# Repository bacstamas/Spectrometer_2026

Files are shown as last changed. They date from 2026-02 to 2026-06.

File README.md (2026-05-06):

# DIY Spectrometer – [Master’s Thesis](https://bacstamas.github.io/Spectrometer_2026/) Project

**Author:** Bács Tamás  
**Program:** Computational Physics MSc  
**University:** Babeș-Bolyai University (UBB), Faculty of Physics  

---

## 📌 Project Overview
This repository contains the complete hardware and software implementation of a low-cost DIY spectrometer. The project is developed as part of my **Master’s Thesis in Computational Physics at UBB**.

The spectrometer is built using an Arduino-based acquisition system, a multispectral sensor, custom electronics, and 3D-printed mechanical parts, with a Java-based desktop application for data visualization and analysis.

---

## 📂 Repository Structure
```
Arduino/        -> Arduino firmware for sensor acquisition and control
Java/           -> Java desktop application (GUI, data processing, visualization)
3DModels/        
 ├── FreeCAD/    -> Editable CAD source files (.FCStd)
 ├── STL/        -> 3D printable models
 └── UFP/        -> Additional fabrication/export formats
Docs/            -> Additional documents, such as images
README.md        -> Project documentation (this file)
.gitignore       -> Git ignore rules
```

---

## 🔧 Required Hardware Components
To build the spectrometer, you need the following components:

### 🧠 Electronics
- **Arduino Uno** – microcontroller for sensor control and data acquisition
- **SparkFun AS7265x Spectral Sensor** – multispectral sensor (visible)
- **BD139 NPN Transistor** – used for driving the light source
- **Light bulb with socket** – approx. **0.2 A at 5 V** (used as broadband illumination source)

### 🖨️ Mechanical Parts
- **3D printed enclosure**  
  (All CAD designs and STL files are included in the `3DModels/` directory.)
- **Spectrophotometer cuvettes**
---

## ⚡ Circuit Diagram
The following circuit is used to drive the illumination source and interface the AS7265x sensor with the Arduino:

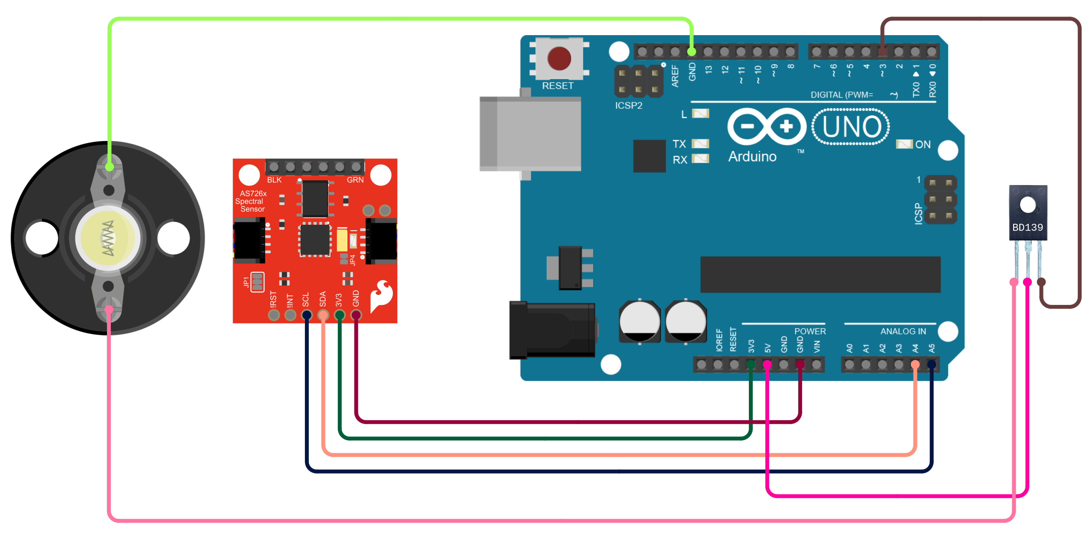
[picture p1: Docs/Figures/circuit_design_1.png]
Spectrometer Circuit Diagram


### Arduino Uno to AS7265x (I2C)

| Arduino Uno Pin | AS7265x Pin | Description |
|---|---|---|
| 5V | VIN / 5V | Sensor power supply |
| GND | GND | Common ground |
| A4 | SDA | I2C data line |
| A5 | SCL | I2C clock line |

### Arduino Uno to BD139 Transistor (Light Bulb Driver)

| Arduino Uno Pin | Component | Description |
|---|---|---|
| D3 (PWM) | BD139 Base | Controls light intensity using PWM |
| 5V | BD139 Collector | Light source supply |
| Light bulb +  | BD139 Emitter | Current flows through bulb |
| Light bulb − | GND | Common system ground |

---

## 🚀 How to Use
1. **Hardware Assembly**
   - Print the 3D models from the `3DModels/STL` folder.
   - Assemble the optical and electronic components according to the circuit diagram.

2. **Arduino Firmware**
   - Open the Arduino project in the `Arduino/` folder.
   - Upload the firmware to the Arduino Uno.

3. **Java Application**
   - Compile and run the Java GUI from the `Java/` folder.
   - The application reads spectral data from the Arduino and visualizes it.
   - Detailed documentation for the Java application can be found here: [Java App Documentation](https://bacstamas.github.io/Spectrometer_2026/JavaDocs/).

---

## 🎓 Academic Context
This project is developed as part of a **Master’s Thesis in Computational Physics** at **Babeș-Bolyai University (UBB), Faculty of Physics**.  
The goal is to design a low-cost spectrometer system and analyze its performance, calibration, and computational data processing methods.

---

## 📧 Contact
Bács Tamás  
tamas.bacs@stud.ubbcluj.ro  
Computational Physics MSc Student  
Babeș-Bolyai University

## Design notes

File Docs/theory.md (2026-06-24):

# Theoretical Background

## Spectroscopy in General

Spectroscopy is the branch of science concerned with the interaction between electromagnetic radiation and matter. When light encounters a substance, several things can happen: it may be transmitted, reflected, scattered, or absorbed, depending on the nature of the material and the wavelength of the radiation. Spectroscopy exploits these interactions to obtain information about the physical and chemical properties of substances [[2]](bibliography.md#ref2). Different regions of the electromagnetic spectrum give rise to different types of spectroscopic techniques. X-ray spectroscopy probes the inner electrons of atoms, infrared spectroscopy reveals molecular vibrations, and UV-visible spectroscopy, which is the focus of this work, involves transitions between electronic energy levels [[1]](bibliography.md#ref1). As shown in **Figure 1**, the visible spectrum occupies a narrow band of wavelengths, situated between the ultraviolet and infrared regions.

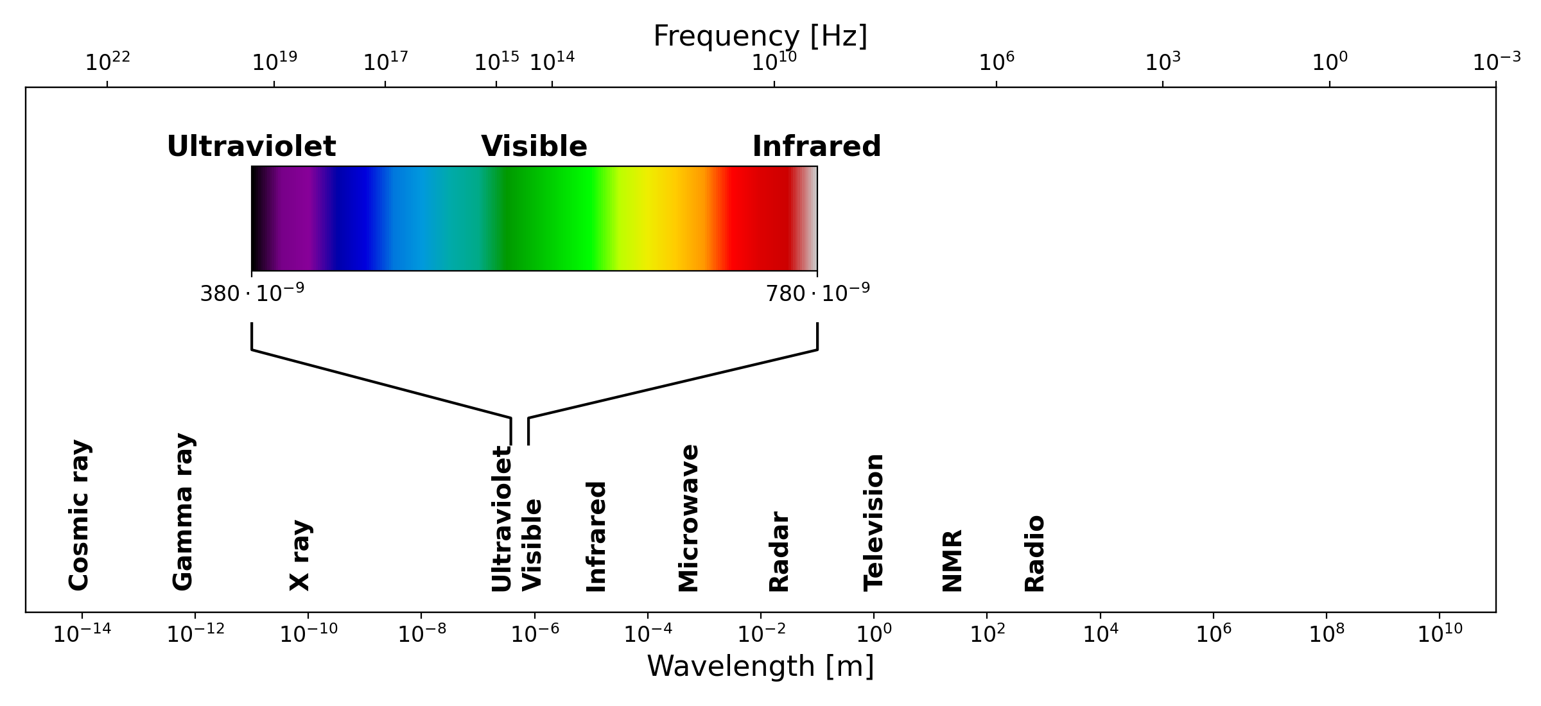
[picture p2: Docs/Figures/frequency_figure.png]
Frequency spectrum

***Figure 1**:The electromagnetic spectrum, showing the full range of radiation from cosmic rays to radio waves. The visible region, spanning approximately 380 to 780 nm, is highlighted with its characteristic color gradient. Both wavelength and frequency scales are shown*

The electromagnetic spectrum spans an enormous range of wavelengths and frequencies, from very short gamma rays at one extreme to long radio waves at the other. The UV-visible region occupies only a small portion of this spectrum, roughly from 190 nm to 800 nm, but it is particularly important because the energy of photons in this range corresponds to the energy differences between electronic states in many molecules. When a photon of the right energy strikes a molecule, it can be absorbed, promoting an electron from a lower energy level to a higher one. The wavelengths at which this absorption occurs are characteristic of the molecular structure, making UV-visible spectroscopy a powerful tool for both qualitative identification and quantitative analysis of chemical substances [[1]](bibliography.md#ref1)[[2]](bibliography.md#ref2).

## Absorption (UV/Vis) Spectroscopy

The quantitative foundation of absorption spectrophotometry is the Beer-Lambert law, which describes the relationship between the concentration of an absorbing substance and the amount of light it absorbs. To understand it, consider a beam of monochromatic light passing through a solution of an absorbing compound held in a transparent container called a cuvette [[10]](bibliography.md#ref10). Some of the light will be absorbed by the molecules in solution, and the rest will be transmitted through to the detector.

The transmittance $T$ of the solution is defined as the ratio of the transmitted light intensity I to the incident light intensity $I_0$:

$$T=\frac{I}{I_0}$$

Transmittance is often expressed as a percentage. However, for analytical purposes, it is more convenient to work with the absorbance $A$, defined as the negative logarithm of the transmittance:

$$A=-\log_{10}(T)=\log_{10}\left(\frac{I_0}{I} \right)$$

The Beer-Lambert law states that the absorbance is directly proportional to both the concentration of the absorbing species and the path length of the light through the sample:

$$A=\varepsilon\cdot l\cdot c$$

where $\varepsilon$ is the molar absorptivity (also called the molar extinction coefficient), a constant characteristic of the absorbing substance at a given wavelength, $l$ is the path length of the light through the sample, as illustrated by the cuvette width in **Figure 2** (1 cm in standard cuvettes), and $c$ is the concentration of the absorbing species. The molar absorptivity has units of $\text{L mol}^{-1} \text{cm}^{-1}$ and can vary enormously between different compounds and different wavelengths [[1]](bibliography.md#ref1).

Beer-Lambert

***Figure 2**: Schematic illustration of the Beer-Lambert law. A beam of incident light with intensity $I_0$ passes through a sample of path length $l$, emerging with reduced intensity $I$ due to absorption by the medium.*

The Beer-Lambert law is the cornerstone of quantitative spectrophotometry. If the molar absorptivity of a substance is known, measuring the absorbance of a solution immediately gives its concentration. In practice, a calibration curve is constructed by plotting the absorbance of standard solutions against their known concentrations [[10]](bibliography.md#ref10), as shown in the right panel of **Figure 3**, allowing for the determination of unknown sample concentrations via linear interpolation. The law holds well at low to moderate concentrations, but deviations can occur at high concentrations, where interactions between molecules begin to affect the absorption behavior, or when the incident light is not truly monochromatic [[1]](bibliography.md#ref1).

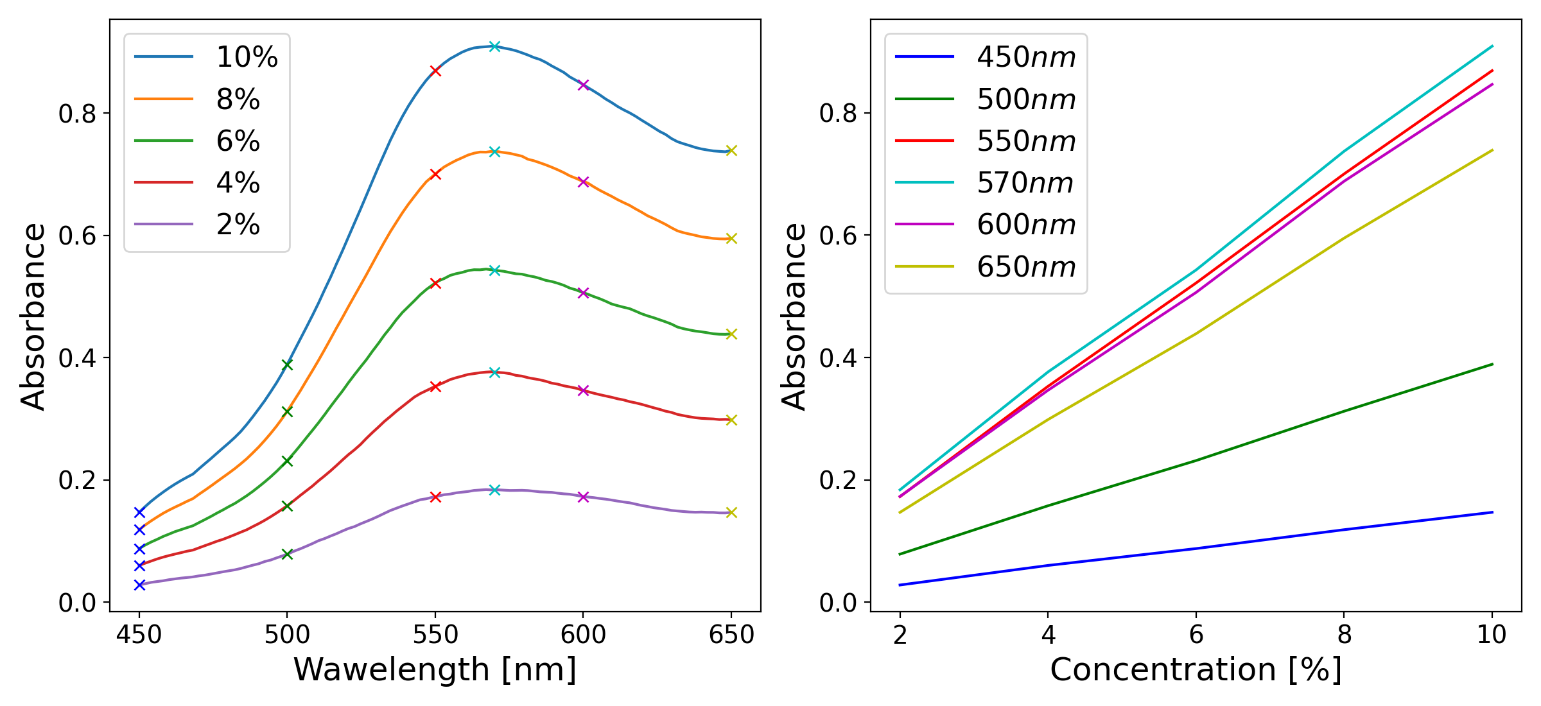
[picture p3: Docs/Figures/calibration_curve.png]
Calibration Curve

***Figure 3**: Left: example absorption spectra of a colored solution at five different concentrations, illustrating the characteristic shape of an absorption band and the increase in absorbance with concentration. Right: absorbance as a function of concentration at six specific wavelengths, illustrating the linear relationship predicted by the Beer-Lambert law.*

### Absorption Spectra and Molecular Structure

When the absorbance of a substance is measured not just at a single wavelength but across a range of wavelengths, the result is an absorption spectrum (a plot of absorbance as a function of wavelength). Each substance has a characteristic absorption spectrum that reflects its molecular structure, specifically the energies of its electronic transitions. The wavelength at which the absorbance reaches its maximum is called $\lambda_{max}$, and quantitative measurements are most sensitive at this wavelength, since small changes in concentration cause the largest changes in absorbance [[1]](bibliography.md#ref1)[[10]](bibliography.md#ref10).

The shape and position of absorption bands in the UV-visible spectrum depend on the electronic structure of the molecule. In organic molecules, the electrons most likely to be involved in UV-visible absorption are the $\pi$ electrons in conjugated systems and the non-bonding lone pair electrons on heteroatoms such as oxygen and nitrogen. As the degree of conjugation in a molecule increases, the energy gap between the ground state and the excited state decreases, and the absorption band shifts to longer wavelengths: a phenomenon known as a bathochromic or red shift. This is why, for example, beta-carotene, which has a long conjugated chain, absorbs strongly in the visible region and appears orange, while simpler molecules with fewer conjugated bonds absorb in the UV and are colorless [[1]](bibliography.md#ref1)[[10]](bibliography.md#ref10).

### Structure and Operation of Absorption Spectrometers

A UV-visible absorption spectrophotometer is an instrument designed to measure the absorbance of a sample as a function of wavelength. Despite the many variations in design and complexity that exist, all spectrophotometers share the same fundamental architecture, consisting of five basic components: a light source, a wavelength selector, a sample holder, a detector, and a readout system [[1]](bibliography.md#ref1). The spatial arrangement and theoretical operation of the primary optical components are schematically represented in **Figure 4**, with the readout system typically integrated into a modern computer interface. 

Spectrometer structure

***Figure 4**: Block diagram of the fundamental components of a single-beam absorption spectrophotometer: a light source, a monochromator for wavelength selection, a sample holder, and a detector.*

The light source must emit radiation across the entire wavelength range of interest with sufficient and stable intensity. For UV-visible spectrophotometry, two types of lamps are commonly used in commercial instruments: a deuterium lamp, which provides continuous radiation in the UV region (190–400 nm), and a tungsten-halogen lamp, which covers the visible and near-infrared region (350–900 nm). Many instruments automatically switch between the two lamps as the wavelength scan crosses the boundary between the UV and visible regions. In lower-cost and educational instruments, white LEDs are a popular alternative, as they are inexpensive, energy-efficient, and emit across much of the visible range, though with a non-uniform spectral output [[1]](bibliography.md#ref1)[[4]](bibliography.md#ref1).

The wavelength selector is the component responsible for isolating a narrow band of wavelengths from the broadband output of the light source. In modern spectrophotometers, this is almost always achieved using a diffraction grating (a flat optical surface ruled with a large number of closely spaced parallel grooves). When light strikes the grating, it is diffracted at angles that depend on its wavelength according to the grating equation:

$$n\lambda=d\sin \theta$$

where $n$ is the diffraction order (typically 1), $\lambda$ is the wavelength of the diffracted light, $d$ is the spacing between adjacent grooves, and $\theta$ is the diffraction angle. By rotating the grating or scanning the detector angle, different wavelengths can be directed onto the sample in sequence, allowing a full spectrum to be recorded. Older instruments used prisms as dispersive elements, but gratings have largely replaced them due to their more linear dispersion and lower cost [[1]](bibliography.md#ref1).

The sample holder is typically a cuvette — a small transparent container with a precisely defined path length, usually 1 cm. Cuvettes for UV measurements must be made from materials that do not absorb UV radiation, such as quartz or fused silica. For measurements confined to the visible region, less expensive plastic or glass cuvettes are perfectly adequate [[1]](bibliography.md#ref1).

The detector converts the transmitted light intensity into an electrical signal. The most common detector type in modern instruments is the photodiode, which generates a current proportional to the incident light intensity. In instruments designed to record a full spectrum simultaneously, an array of photodiodes (known as a photodiode array or PDA) can be used, replacing the need to scan through wavelengths mechanically. Photomultiplier tubes (PMTs), which offer much higher sensitivity, are used in high-end research instruments. For educational and low-cost devices, simpler detectors such as light-dependent resistors (LDRs) or phototransistors are also viable options [[1]](bibliography.md#ref1)[[4]](bibliography.md#ref4).

Finally, the readout system processes the electrical signal from the detector and presents the result to the user. In modern instruments this is handled entirely by software running on a connected computer, which can display the spectrum, perform baseline corrections, and carry out quantitative calculations automatically. In simpler home-built instruments, the detector signal is often read directly with a digital multimeter and the absorbance calculated by hand or with a simple script [[1]](bibliography.md#ref1)[[8]](bibliography.md#ref8).

It is worth noting the distinction between single-beam and double-beam instrument designs. In a single-beam spectrophotometer, the sample and the blank (a reference solution, typically the pure solvent) are measured sequentially, and the ratio of their signals gives the transmittance. In a double-beam instrument, the light is split into two paths (one through the sample and one through the reference) and both are measured simultaneously. The double-beam design is more stable against fluctuations in the light source intensity and is therefore preferred in research-grade instruments, although single-beam designs are perfectly adequate for many educational and routine analytical applications [[1]](bibliography.md#ref1)[[2]](bibliography.md#ref2).

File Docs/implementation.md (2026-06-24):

# Design and Implementation of the Spectrophotometer
## Hardware

### Idea

The starting point for the hardware design was the desire to build a functional absorption spectrophotometer that was as simple and inexpensive as possible, while remaining open to future refinement and improvement. A key decision in this direction was the choice of the SparkFun [AS7262](https://cdn.sparkfun.com/assets/f/b/c/c/f/AS7262.pdf) Visible Spectral Sensor as the core detection element. This sensor measures light intensity in six fixed channels across the visible spectrum, centered at 450, 500, 550, 570, 600, and 650 nm, and communicates digitally with a microcontroller via I2C. Its main advantage for this application is that it eliminates the need for a diffraction grating and a rotating wavelength selector entirely, the spectral discrimination is handled internally by the sensor itself. This greatly simplifies the optical layout and reduces the number of precision components required, at the cost of spectral resolution, since the instrument can only sample six discrete wavelengths rather than a continuous spectrum.

As the microcontroller, an [Arduino Uno](https://docs.arduino.cc/resources/datasheets/A000066-datasheet.pdf) was chosen. This is a natural pairing with the AS7262 sensor, as the Arduino provides the I2C interface needed to communicate with it, can supply the sensor with power, and can transfer the acquired data to a PC via its USB connection. The Arduino Uno is also widely available, inexpensive, and well documented, making it a suitable platform for an educational instrument.

For the light source, an incandescent bulb was preferred over an LED. While LEDs are cheaper and more energy efficient, their emission spectrum is strongly peaked at specific wavelengths, which can result in uneven illumination across the six detection channels of the sensor. An incandescent bulb, by contrast, emits a broad and relatively smooth blackbody-like spectrum across the entire visible range, providing more uniform illumination of all channels. The chosen bulb is a Goobay product with an E10 socket, rated at 3.5 V and 0.2 A, giving a power consumption of 0.7 W. This low current draw is important, as the 5V power pin of the Arduino Uno can supply a limited current, and exceeding it risks damaging the board.

The optical layout follows a straightforward single-beam transmission configuration. Light from the bulb passes through a vertical slit, which collimates it into a narrow beam. This beam then passes through the cuvette, which holds the sample solution. A second slit placed after the cuvette further restricts the beam before it reaches the AS7262 sensor. Standard commercial cuvettes with a 10×10 mm inner cross section and 1 cm path length were used, consistent with the standard path length assumed in Beer-Lambert law calculations. The structural frame holding all of these components together was designed in 3D modeling software and printed using a high-precision 3D printer with PLA filament, resulting in a compact enclosure slightly smaller than a 6×10×25 cm block.

### Obstacles

he development of the hardware went through two main iterations, driven by a series of practical problems encountered during testing.

The first version of the frame was modular in design, meaning that the positions of the light source, the slits, and the sensor could be adjusted along the optical axis. This was useful in the early stages of development, as it allowed the optimal spacing between components to be found experimentally. However, this first version had no cover or enclosure around the optical path, meaning that ambient light from the room could reach the sensor and contaminate the measurements. As a result, all measurements with this version had to be performed in a darkened room, which was clearly impractical for regular use.

A further issue that emerged during testing was the need to control the intensity of the light source. The AS7262 sensor has a fixed integration time and gain setting for each measurement, and if the light reaching it is too intense, the sensor saturates and the readings become unreliable. A way to reduce the light intensity without modifying the optical layout was therefore needed.

Finally, the PLA filament used for 3D printing presented an unexpected problem. The filament available was blue in color, and it turned out to be partially translucent to ambient light, allowing a non-negligible amount of stray light to penetrate the walls of the enclosure even in the second, closed version of the frame.

### Implementation

The second version of the frame addressed the problems identified during testing with the first. All components (the light source, the two slits, the cuvette holder, and the sensor) were given fixed, precisely dimensioned positions inside a closed enclosure, based on the optimal spacing determined during the first phase. The enclosure included a removable cover to allow access to the cuvette holder for changing samples, while keeping the rest of the optical path shielded from ambient light. A dedicated bay was also added to securely mount the Arduino Uno board, positioned with the USB Type-B connector accessible from the outside of the enclosure, so that the connection to the PC could be made without opening the instrument. Crucially, the Arduino was physically separated from the optical components inside the box, so that the indicator LEDs on the board would not interfere with the sensor readings. The internal structure of the assembled spectrometer is shown in **Figure 5**. 

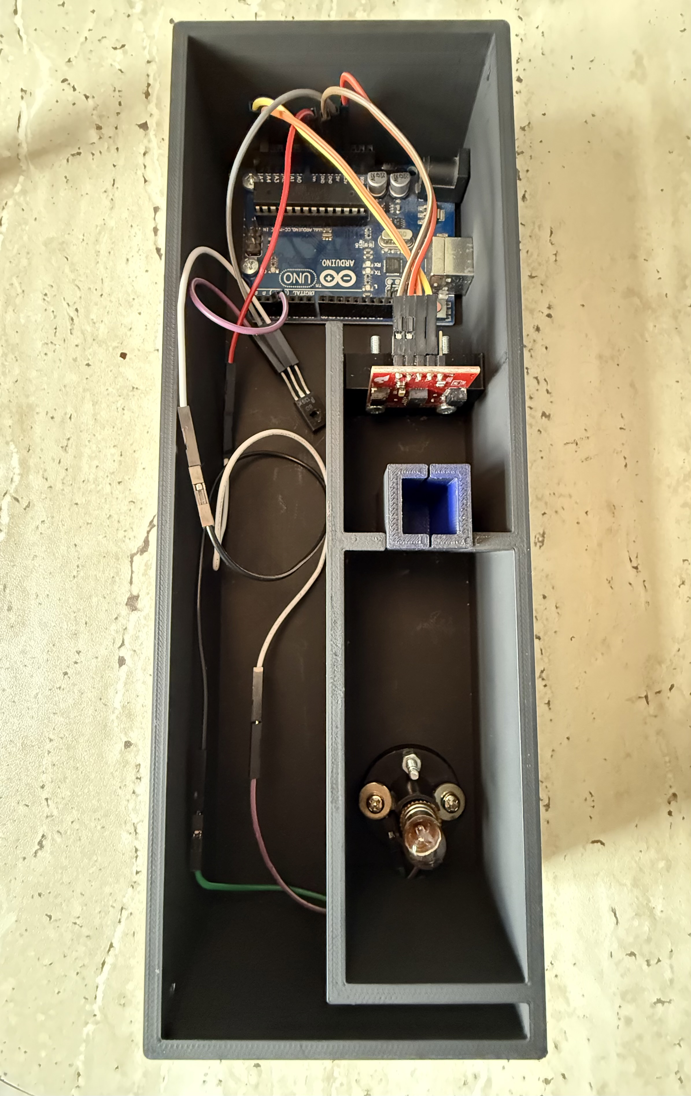
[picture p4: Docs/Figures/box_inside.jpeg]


***Figure 5**: Photo of the inside of the spectrometer.*

To solve the problem of stray light penetrating through the blue PLA walls, the exterior and interior surfaces of the enclosure were painted with a matte black paint of the type used industrially to produce surfaces with near-unity emissivity for thermal imaging applications. This paint effectively blocked the residual light transmission through the plastic walls and also minimized internal reflections within the enclosure.

The light intensity control problem was solved by adding a [BD139](https://share.google/5DOaTHuip5NTmbAFO) NPN bipolar transistor to the circuit. The transistor was wired with its collector connected to the Arduino's 5V supply pin, its emitter connected to the positive terminal of the light bulb, and the negative terminal of the bulb connected to the Arduino's ground. The base of the transistor was driven by pin 3 of the Arduino, which is a PWM-capable output. By varying the duty cycle of the PWM signal, the effective voltage across the bulb can be adjusted continuously, allowing the light intensity to be tuned to a level that keeps the sensor within its linear operating range without saturating it. This simple addition significantly improved the reliability and reproducibility of the measurements. See **Figure 6** for the circuit diagram.

Spectrometer structure

***Figure 6**: Photo of the inside of the spectrometer.*

Several sub-components, including the sensor holder, the cuvette holder, and the box cover, went through additional minor refinements beyond the two main frame iterations, as small geometric adjustments were needed to improve the fit and reduce stray light leakage around the edges. The final assembled instrument is a compact, self-contained device that can be connected to any computer via a standard USB cable and operated without any need for a darkened environment.

## Software

The software component of the spectrophotometer system consists of two separate programs: the firmware running on the Arduino microcontroller, which is responsible for directly operating the sensor and acquiring data, and a Java desktop application running on the PC, which serves as the interface between the user and the instrument. The two communicate through a serial connection over USB.

The **Arduino firmware** is intentionally kept simple and lightweight. On startup, it initializes the AS7262 sensor and sets a default configuration for the measurement parameters. It then enters a waiting loop, listening for commands arriving through the serial port.

When a measurement is requested, the command arrives as a formatted string specifying all relevant parameters: integration time, gain, number of averages, measurement mode, and light intensity. The firmware parses this string, applies the specified settings to the sensor, and adjusts the PWM signal on pin 3 to set the light source intensity accordingly. It then performs the measurement the requested number of times and computes the average across repetitions for each of the six spectral channels. The result is sent back to the PC as a single comma-separated line of six floating point values, one per channel.

The AS7262 sensor library supports two measurement modes: a raw mode, which returns the unprocessed digital counts from each photodetector channel, and a calibrated mode, which applies internal corrections to return values in units of calibrated irradiance. Both modes are accessible through the firmware and can be selected by the user from the PC software.

The **PC-side software** is written in Java, a choice motivated by several practical considerations. Java is inherently cross-platform, the same application can run on Linux, Windows, and macOS without significant modification, and it lends itself naturally to well-structured, object-oriented design that can be extended and maintained over time. The application was developed and tested on Linux but is intended to be portable across operating systems. It uses the *jSerialComm* library for serial port communication, the *XChart* library for data visualization and the *Jackson* library for handling JSON files.

The architecture of the application is organized around a small set of well-defined classes, each with a clear responsibility. This separation of concerns makes the codebase easy to navigate and extend without requiring a complete redesign.

### Structure

The *Spectrometer* class is the core of the application. It is responsible for all communication with the Arduino hardware. On instantiation, it automatically scans the available serial ports on the system (using the *jSerialComm* library) and identifies the connected Arduino by checking port descriptors and system names. Once connected, it configures the serial port parameters (baud rate, data bits, stop bits, parity) opens the connection, and flushes any startup messages sent by the Arduino. It exposes methods to configure the measurement parameters and to trigger measurements, handling the sending of the formatted command string and the reception and parsing of the response. Each call to the measurement method can request multiple spectra in sequence, each acquired with on-board averaging by the Arduino.

The *MeasurementSet* class acts as a container for all data associated with a single acquisition session. It stores the list of individual spectra recorded during that session, the full set of measurement parameters used, and a unique name composed of a user-defined label and the date and time of acquisition. It provides methods for computing the mean and standard deviation across the recorded spectra for each channel, for formatting this information as a readable string, and for saving the entire measurement set to a JSON file or loading it back from one. JSON format was chosen because it is human-readable and easy to handle.

The *Visualizer* class handles all data visualization. It takes a *MeasurementSet* as input and can produce two types of charts: a spectrum plot showing the intensity values across the six channels of the sensor, and an absorption spectrum computed from two separate measurement sets representing the reference and the sample. The absorbance at each channel is calculated according to the Beer-Lambert law as:

$$A=-\log_{10} \left(\frac{I_{sample}}{I_{reference}}\right)$$

where $I_{sample}$ and $I_{reference}$ are the mean intensities of the sample and reference measurements at each channel respectively. The *Visualizer* class uses the *XChart* library to produce the actual chart objects, which are then embedded in the GUI.

The remaining classes handle the graphical user interface. The *Main* class serves as the application entry point, launching the GUI on the appropriate thread. The *MainWindow* class implements the main application window, while the remaining classes manage the panels, menus, and dialogs, and handle specific user interactions.

### Features

The main window of the application is organized around a central list that displays all measurement sets currently loaded in memory, each identified by its unique name. From the main window, the user can connect to the spectrometer and configure the measurement parameters through a dedicated dialog, which provides input fields for integration time, gain, number of averages, number of measurements, measurement mode, and light intensity. Once configured, a measurement can be triggered with a single button press. The acquired measurement set is automatically added to the list and displayed in a text area showing its parameters and statistics.

Measurement sets can be saved to and loaded from plain text files, allowing results to be stored for later analysis or shared between sessions. The user can also load previously saved measurements without connecting to the hardware, making it possible to perform data analysis and visualization independently of the instrument.

For visualization, two separate plot types are available. The spectrum plot displays the raw or calibrated intensity values across the six sensor channels for a selected measurement set, while the absorption plot computes and displays the absorbance spectrum from a user-selected reference and sample pair. Both plot types offer configurable options accessible through dialog windows: the x-axis can be displayed in wavelength (nm) or in frequency (THz), the y-axis values can be shown as raw values or normalized to the maximum, the plot style can be switched between a line curve and a bar chart, and error bars representing the standard deviation across repeated measurements can be toggled on or off.

### Data Processing and Calibration

The data processing performed by the software is deliberately straightforward, reflecting the educational purpose of the instrument. The primary computation is the averaging of repeated spectra, which is handled partly by the Arduino firmware, which averages multiple sensor readings within a single acquisition, and partly by the *MeasurementSet* class, which computes the mean and standard deviation across multiple sequential acquisitions requested by the user. This two-level averaging scheme gives the user flexibility in balancing measurement speed against statistical reliability.

The absorbance calculation follows directly from the Beer-Lambert law, as described above. No additional baseline correction or spectral smoothing is applied, keeping the processing chain transparent and easy to follow.

## Experimental Results and Validation

With the hardware and software components completed, a series of experiments was carried out to characterize the performance of the instrument and to validate its suitability for quantitative absorbance measurements.

### Stray Light Test

The first test performed was aimed at verifying that the closed enclosure of the spectrophotometer effectively excludes ambient light. An empty cuvette was placed in the cuvette holder, the cover of the box was closed, and the light source intensity was set to 0, meaning the bulb was switched off via the PWM control. Under these conditions, repeated measurements returned a value of exactly zero on each of the six channels of the sensor. This result confirms that no stray or ambient light reaches the detector when the light source is off, validating the effectiveness of the matte black coating applied to the interior of the enclosure and ruling out the presence of any light leaks through the housing.

### Reproducibility Test

To assess the reproducibility of the measurements, a solution of yellow food coloring at a concentration of $2.5\%$ was prepared and measured repeatedly. Ten independent measurement sets were acquired, each consisting of 100 individual measurements per channel (integration time: 100 ms, gain: 16, averaging: 1, mode: raw, light intensity: 100). All ten sets were plotted together, as shown in **Figure 7**, where each of the six channels is represented by ten overlapping traces of 100 points each.

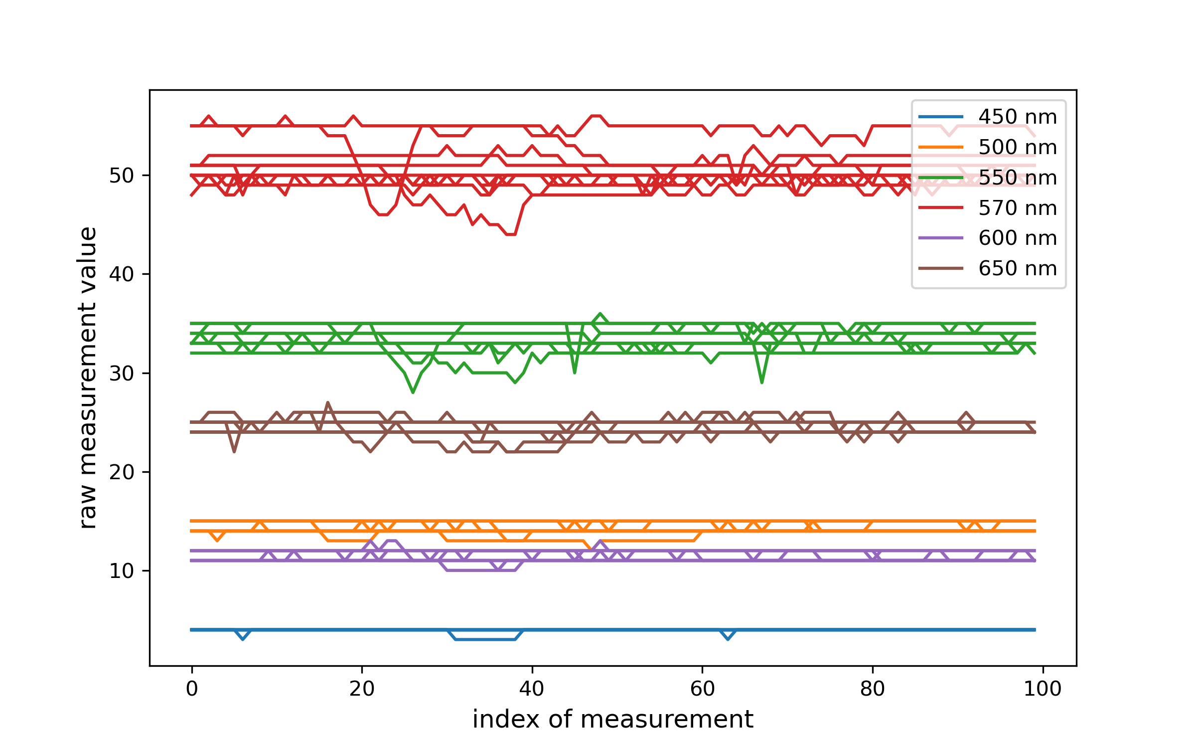
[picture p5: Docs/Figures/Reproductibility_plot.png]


***Figure 7**: Raw measurement values recorded across the six channels of the AS7262 sensor (450, 500, 550, 570, 600, and 650 nm) for ten independently acquired measurement sets of a $2.5\%$ yellow food coloring solution, each consisting of 100 individual measurements.*

The plot shows that the measured values remain clustered around a stable baseline for each channel, with some random scatter present throughout the dataset. Averaging across all 1000 individual measurements per channel (10 sets × 100 measurements), the mean raw values obtained were *{3.99, 14.251, 33.428, 50.629, 11.336, 24.334\}* for the *450, 500, 550, 570, 600* and *650* nm channels respectively, with corresponding standard deviations of *{0.099, 0.522, 1.101, 2.004, 0.501, 0.696\}*. The relative standard deviation remains below approximately $4\%$ for every channel, which indicates a satisfactory level of reproducibility for an instrument of this cost and complexity. This noise may be attributable to small imperfections such as scratches on the cuvette surface and slight variations in its exact positioning within the holder between insertions.

### Long-Term Stability Test

A further test was conducted to check whether the solution itself remained stable over time, an important consideration since sedimentation or settling of the food coloring could introduce a systematic drift in absorbance unrelated to the instrument's performance. The same yellow food coloring solution and the same measurement parameters used in the reproducibility test were employed. A cuvette containing the solution was measured once, left undisturbed inside the instrument for 24 hours, and then measured again without being touched or repositioned in between. The difference between the two measurements was found to be smaller than the standard deviations already observed in the reproducibility test, indicating that no significant settling or degradation of the solution occurred over this timescale, and that any short-term drift in the instrument's readings is dominated by the handling-related noise identified above rather than by sample instability.

### Calibration Curves

Finally, the linearity of the instrument's response was tested by preparing a series of yellow food coloring solutions at concentrations ranging from $0.8\%$ to $10\%$, and measuring the absorbance of each at all six sensor channels. The resulting calibration curves are shown in **Figure 8** (one subplot for each channel) together with a linear best-fit line.

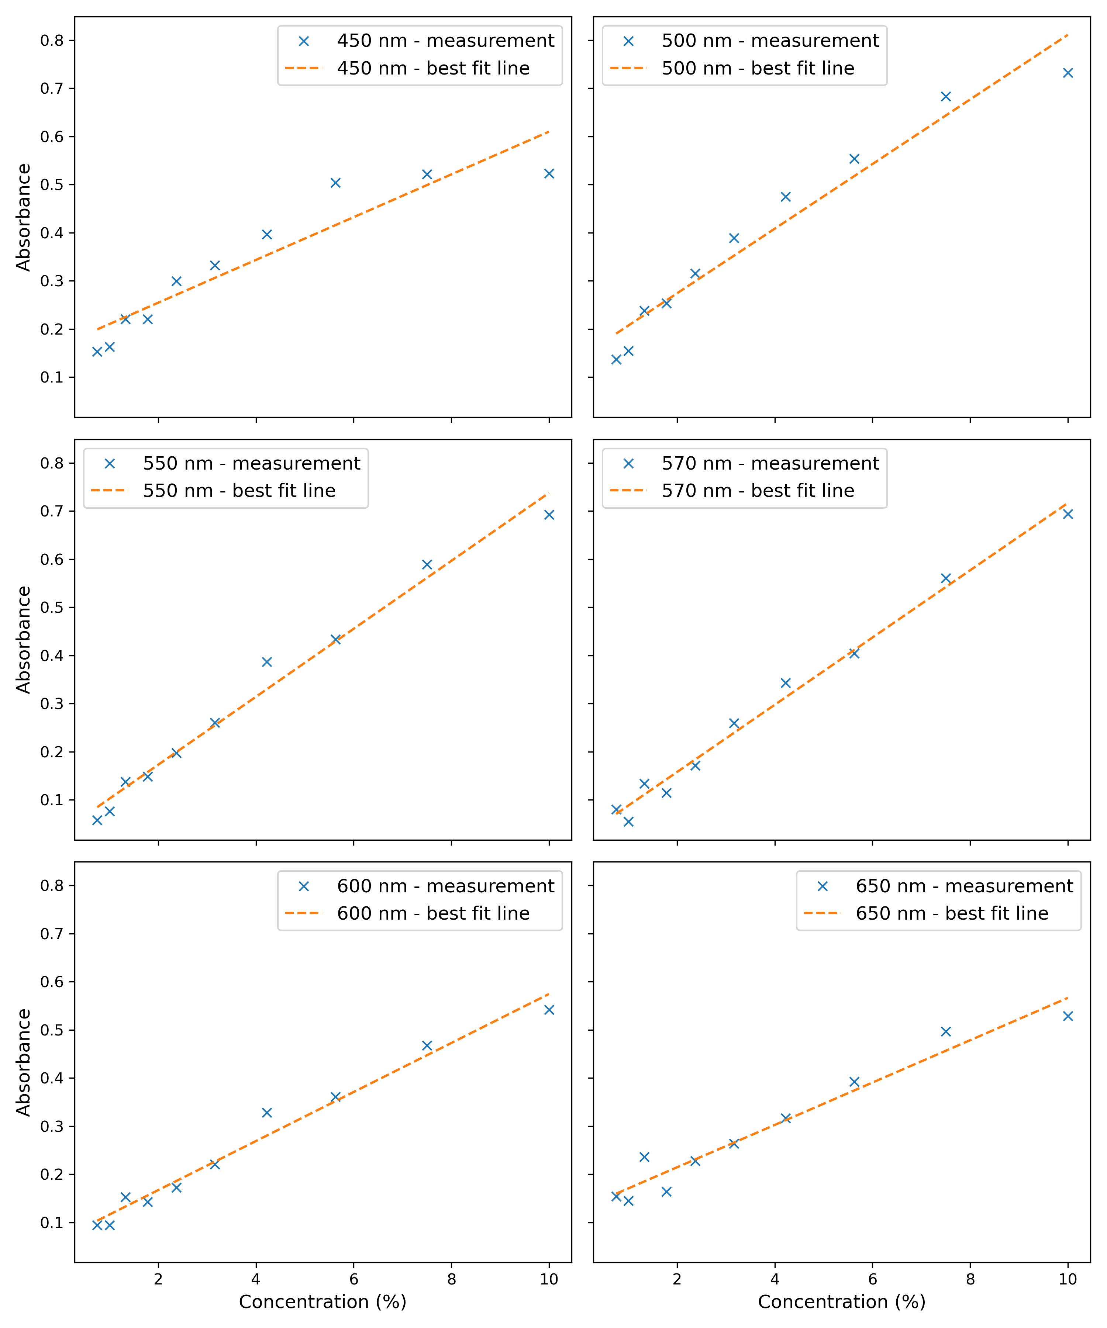
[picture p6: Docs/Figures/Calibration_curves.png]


***Figure 8**: Six calibration curves showing absorbance against concentration ($\%$), along with their corresponding best-fit lines, at each of the sensor's wavelengths.*

Across all six channels, the measured absorbance values follow the linear trend predicted by the Beer-Lambert law reasonably well, particularly in the central concentration range. Some scatter around the fitted line is visible, which is consistent with the absolute measurement noise identified in the reproducibility test. The channels at *550, 570* and *600* nm, which are closer to the absorption maximum of the yellow dye, display the clearest linear behavior and the largest overall absorbance range, while the *450* nm channel, which lies further from the absorption peak, shows comparatively more scatter relative to its smaller dynamic range. Overall, these results confirm that the constructed instrument is capable of producing calibration curves with a clearly recognizable linear character across the entire visible range covered by the sensor, supporting its intended use for quantitative concentration measurements in an educational context.

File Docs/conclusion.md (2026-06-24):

# Conclusion
The primary objective of this thesis was the design, construction, and validation of a low-cost absorption spectrophotometer intended for educational use. The developed instrument combines simple hardware with dedicated software for data acquisition, visualization, and absorbance calculation. Experimental testing demonstrated that the spectrometer is capable of producing reproducible measurements and calibration curves that follow the linear behavior predicted by the Beer-Lambert law. While the measurements exhibit a non-negligible level of noise, the results show that the instrument is sufficiently reliable for educational and demonstration purposes, provided that appropriate care is taken during sample preparation and measurement.

One of the main strengths of the instrument is its combination of low cost and transparency. Unlike commercial spectrophotometers, whose internal operation is often hidden from the user, the present design exposes the essential elements of an absorption measurement system and makes the underlying physical principles easier to understand. As a result, the spectrometer is well suited for use in secondary-school and undergraduate laboratory activities. Students can gain practical experience with solution preparation, reference measurements, absorbance calculations, the construction of calibration curves, and the quantitative determination of concentrations. More advanced educational projects could even include the determination of the molar absorptivity of a substance through Beer-Lambert analysis.

Beyond its use as a measurement instrument, the reproduction of the spectrometer itself could serve as a valuable educational project for physics students at the BSc or MSc level. Constructing the device requires engagement with several important areas of modern scientific and engineering practice, including absorption spectroscopy, 3D design and printing, microcontroller programming, object-oriented software development, and experimental testing. The process of building and validating the instrument provides a deeper understanding of both the physical principles and the practical challenges involved in spectroscopic measurements.

Although the instrument successfully fulfills its intended educational purpose, several opportunities for further development remain. One possible improvement would be the replacement of the AS7262 sensor with a sensor offering a larger number of spectral channels, increasing the spectral resolution of the measurements. Another possibility would be to adopt a more traditional spectrometer architecture based on a rotatable diffraction grating and a simpler photodetector, allowing the acquisition of a continuous spectrum rather than measurements at six discrete wavelengths. Such modifications could improve the analytical capabilities of the instrument while preserving its educational value.

A particularly promising direction for future development would be the replacement of the Arduino Uno with an ESP32 microcontroller. The additional processing power and built-in Wi-Fi connectivity of the ESP32 would make it possible to implement the user interface as a web application hosted directly by the instrument. In such a design, users could access the spectrometer through any device equipped with a web browser, without the need to install dedicated software. This would simplify deployment in classroom environments, reduce platform-dependence, and further increase the accessibility of the system.

In conclusion, the developed spectrophotometer demonstrates that quantitative absorption measurements can be achieved with inexpensive and widely available components. Although it cannot compete with commercial instruments in terms of precision or spectral resolution, it successfully fulfills its intended role as an educational tool and provides a practical platform for teaching both spectroscopy and scientific instrumentation.

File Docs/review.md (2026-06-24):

# Review of Low-Cost / DIY Spectrophotometers

The development of low-cost and home-built spectrophotometers has been an active area of interest in the educational and scientific community for several decades. The motivations behind these efforts are clear: commercial instruments are often prohibitively expensive for schools and smaller institutions, and even when available, they offer little insight into the physical principles of the measurement. A wide variety of designs have been proposed over the years, differing in complexity, cost, target audience, and performance. This section reviews the most relevant examples from the literature, with particular attention to the design choices made and the lessons that can be drawn for the present work.

One of the earliest and most accessible designs is that described by Lema et al. [[6]](bibliography.md#ref6), who built a spectrophotometer from components readily available to anyone: a halogen flashlight as the light source, a compact disc (CD) as the diffraction element, a light-dependent resistor (LDR) as the detector, and a standard digital multimeter for readout. The entire assembly was mounted in a cardboard box, with two simple slits used to collimate the diffracted light onto the detector. Despite its extreme simplicity, this device was capable of producing recognizable absorption spectra and calibration curves for several biochemically relevant substances, including chlorophyll, starch, and proteins. The authors demonstrated its use in a series of teaching experiments in a biosciences course, showing that meaningful quantitative results could be obtained even with such minimal means. The main limitation of this design is its poor wavelength resolution (rotating the CD by a single degree corresponds to a wavelength change of approximately 25 nm) and the fact that it provides resistance readings rather than direct absorbance values. Nevertheless, it remains a compelling demonstration of how far ingenuity can go in replacing expensive equipment [[6]](bibliography.md#ref6).

A more structured approach was taken by Knagge and Raftery [[7]](bibliography.md#ref7), who designed a LEGO-based spectrophotometer for use in a graduate-level chemical instrumentation course at Purdue University. Their instrument incorporated a miniature filament lamp as the light source, a convex lens and an infrared filter for light conditioning, a 1000 lines/mm transmission diffraction grating, a spring-loaded rotating mirror for wavelength selection, a silicon photodetector, and an amplifier circuit connected to a digital multimeter. The use of LEGO bricks as optical mounts was motivated by their precise manufacturing tolerances, modularity, and mechanical stability, which make them well suited to holding optical components in alignment. The instrument achieved a wavelength resolution of approximately 8 nm and was used to record absorption spectra and calibration curves for potassium permanganate. Compared to a commercial Spectronic 20 instrument, the home-built device showed higher stray light levels and a higher limit of detection, but its calibration curves displayed similar linearity. The total cost was approximately 200 USD. The authors emphasized that the educational value of the device lay not only in its use, but in the process of construction itself, through which students gained practical experience with the optical and electronic modules that make up any analytical instrument [[7]](bibliography.md#ref7).

Building on the LEGO concept but targeting a much younger and less specialized audience, Albert, Todt, and Davis [[8]](bibliography.md#ref8) developed a significantly simpler and cheaper LEGO spectrophotometer designed for use in high school physics and chemistry classes. Their design used a white LED as the light source, a single lens for collimation, a 1000 lines/mm slide-mounted diffraction grating, and a photodiode mounted on a rotatable arm for wavelength selection, with a digital multimeter as the readout. The entire apparatus was built on a standard LEGO baseplate and could be assembled and optimized in approximately 45 minutes. The total cost was around 25 USD, roughly one eighth of the cost of the Knagge and Raftery design. Despite its simplicity, the device produced absorbance measurements in close agreement with those from a commercial Ocean Optics USB2000+ spectrophotometer over the typical working range of absorbance values up to about 1, and was capable of recording full visible absorption spectra between approximately 420 and 660 nm. The authors noted that the use of familiar toy materials made the activity engaging for students, and that the transparent design effectively exposed the physical principles that are hidden in commercial black-box instruments [[8]](bibliography.md#ref8).

A very different approach is represented by the work of Wang et al. [[9]](bibliography.md#ref9), who demonstrated a smartphone-based spectrometer for colorimetric biosensing applications. Their device used the built-in LED flash of a smartphone as the light source, a compact disc fragment as the diffraction grating, and the smartphone's CMOS camera as the detector. The entire optical assembly was compact and required no external components beyond a simple sample cell. The smartphone camera captured the dispersed spectrum as an image, which was then processed using a dedicated Android application to extract the absorbance spectrum. The device was tested for the detection of glucose using an enzymatic colorimetric assay and for the detection of cardiac troponin I using peptide-functionalized gold nanoparticles, achieving limits of detection comparable to those of commercial bench-top instruments. While this design is more oriented toward portable point-of-care diagnostics than classroom education, it illustrates the remarkable potential of consumer electronics as spectroscopic platforms, and it highlights the growing role of smartphones and digital cameras as detectors in low-cost spectrophotometry [[9]](bibliography.md#ref9).

González-Morales et al. [[3]](bibliography.md#ref3) presented a portable low-cost UV-Vis spectrophotometer specifically designed for field measurements of environmental contaminants, with a particular application to the detection of mercury ions in water using a synthesized chemosensor. Their instrument operated in the visible range from 400 to 700 nm and used a 1 W white LED as the light source, a DVD-derived diffraction grating mounted on a stepper motor for automated wavelength scanning, and a TEMT6000 phototransistor as the detector. The entire device was housed in a 3D-printed black enclosure and controlled by an Arduino microcontroller, which performed the wavelength sweep, acquired the detector signal, computed the absorbance, and transmitted the data to a computer. Two independent sample chambers allowed simultaneous measurement of the sample and a reference, improving stability. The total cost of the device was below 86 USD. Absorbance measurements agreed with those from a commercial Cary 60 spectrophotometer with error percentages below $10\%$ for most concentrations, and below $5\%$ for the mercury detection experiments. This design is particularly noteworthy for its level of integration and automation, demonstrating that a microcontroller-based instrument can approach commercial performance at a small fraction of the cost [[3]](bibliography.md#ref3).

Finally, the Viking spectrophotometer developed by Kolesnichenko et al. [[5]](bibliography.md#ref5) represents one of the most pedagogically sophisticated examples in the recent literature. Rather than aiming for maximum analytical performance, this design prioritized the learning experience above all else. The instrument was built from wooden holders, inexpensive magnifying glass lenses, a white LED light source with a replaceable aluminum foil slit, and a transmission diffraction grating mounted in a slide frame. Crucially, no fixed housing was used, all components were freely positioned on a flat table, allowing students to experiment with different configurations, observe the effects of misalignment, and develop genuine physical intuition. The spectrum was projected onto a white cardboard screen and photographed with a smartphone camera for digitization. The device supported both absorption and fluorescence measurements and was successfully deployed across a wide range of educational levels, from high school outreach activities to Master and PhD level courses at Lund University. Its total material cost was approximately 14 euros per set. The authors reported that engagement with the Viking spectrophotometer measurably improved the quality of students' laboratory reports and their confidence when subsequently operating professional instruments [[5]](bibliography.md#ref5).

Taken together, these examples illustrate that low cost and high educational value are not mutually exclusive, and that the integration of a microcontroller with dedicated software can dramatically extend the functionality of a home-built device without greatly increasing its cost. These considerations have directly shaped the design decisions described in the following chapter.

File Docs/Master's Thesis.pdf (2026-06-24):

## BABES, -BOLYAI UNIVERSITY

# Master’s thesis

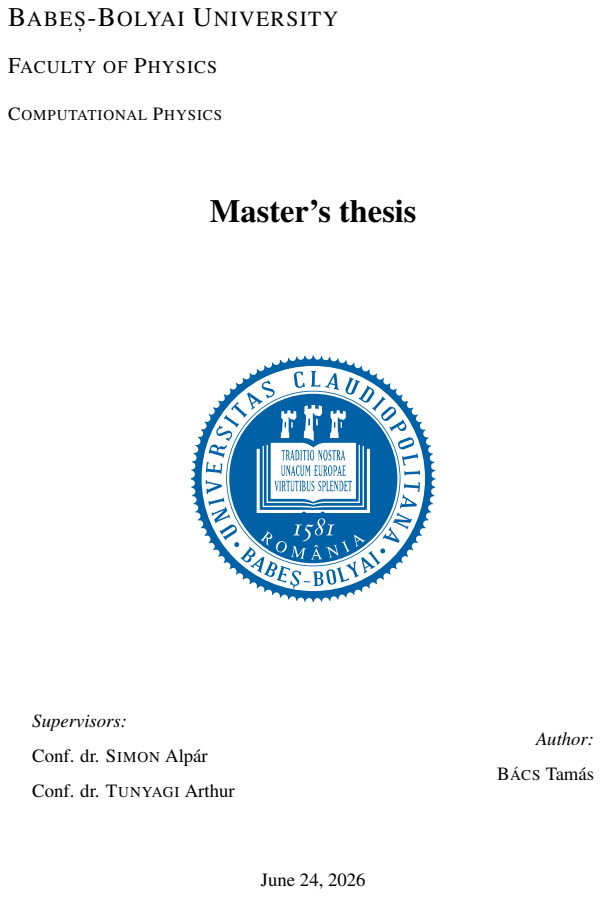
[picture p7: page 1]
COMPUTATIONAL PHYSICS; Supervisors:; Author:; BÁCS Tamás; June 24, 2026

FACULTY OF PHYSICS

Conf. dr. SIMON Alpár

Conf. dr. TUNYAGI Arthur

## BABES, -BOLYAI UNIVERSITY

# Master’s thesis

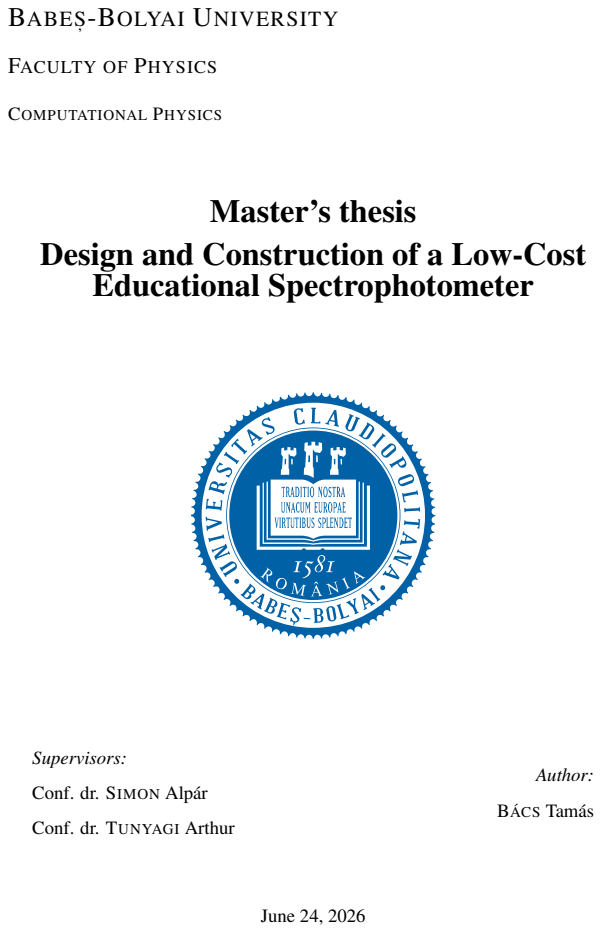
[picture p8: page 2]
COMPUTATIONAL PHYSICS; Supervisors:; Author:; BÁCS Tamás; June 24, 2026

FACULTY OF PHYSICS

Design and Construction of a Low-Cost
Educational Spectrophotometer

Conf. dr. SIMON Alpár

Conf. dr. TUNYAGI Arthur

## Contents

Introduction and Objectives | 4
1 Theoretical Background | 6
2 Review of Low-Cost / DIY Spectrophotometers | 12
3 Design and Implementation of the Spectrophotometer | 15
Conclusion | 26
References | 28

BÁCS Tamás | Design and Construction of a Low-Cost Educational Spectrophotometer

## Introduction and Objectives

Since vision is one of our most important and highly developed senses, it is natural that humans

have long sought to build instruments capable of performing similar tasks in a quantitative and

objective manner. Just as the human eye can often provide a qualitative impression of whether

a sample of water is clean or contaminated, a spectrophotometer can analyze the interaction of

light with matter and provide quantitative information about the composition and concentration of

substances dissolved in a solution. This is widely used in chemistry, biology, medicine, and en-

vironmental monitoring. In particular, UV-visible (UV-Vis) absorption spectrophotometry is built

on the Beer-Lambert law, which states that the amount of light absorbed by a solution is propor-

tional to the concentration of the absorbing substance. This makes it an indispensable tool in both

research and educational settings, where it underlies experiments ranging from the quantification

of biomolecules to the study of reaction kinetics [1][2].

Despite its importance, access to absorption spectrophotometry is far from universal. Com-

mercial UV-Vis spectrophotometers, while offering excellent performance, are expensive instru-

ments that many schools and universities, particularly those with limited budgets, cannot afford [3].

Beyond the financial barrier, modern commercial instruments present a further challenge in edu-

cational contexts: they function as so-called "black boxes", hiding from the user the physical

principles that underlie the measurement. Students who interact only with polished commercial

devices are often left with little understanding of how a spectrum is actually generated, what role

the diffraction grating plays, or why alignment and calibration matter [4][5]. This gap between

instrument use and instrument understanding is a genuine obstacle to deep learning in physics and

chemistry education.

In response to these challenges, a growing body of work over the past two decades has explored

the construction of low-cost, home-built spectrophotometers for educational use. These range from

very simple devices assembled from compact discs, flashlights, and cardboard [6], to more refined

systems built from LEGO bricks [7][8], 3D-printed parts [4], or smartphone platforms [9]. A com-

mon finding in this literature is that building an instrument from scratch (selecting components,

aligning optics, calibrating the wavelength scale, and troubleshooting) provides a qualitatively

richer learning experience than simply operating a commercial device. Students who build their

own spectrophotometers develop a hands-on understanding of diffraction, Beer-Lambert behavior, and sources of experimental error that would otherwise remain abstract [5][8]. At the same time,

these devices can bring quantitative spectroscopic measurement within financial reach of institu-

tions that would otherwise have none [6].

The present thesis is situated within this context. The goal was to design, construct, and char-

acterize a low-cost absorption spectrophotometer intended primarily for educational use. The in-

strument is developed with transparency in mind: every component is chosen and arranged so as

to make the underlying physics as visible and understandable as possible to anyone assembling

or using it. Alongside the hardware, a dedicated software system is developed to handle data

acquisition, wavelength calibration, and the computation of absorbance spectra [4].

More specifically, the thesis begins by reviewing the theoretical foundations of UV-Vis ab-

sorption spectroscopy, including the Beer-Lambert law and the general operating principles of

spectrophotometric instruments. It then surveys existing low-cost and DIY spectrophotometer de-

signs from the literature, identifying key design choices and their trade-offs. The bulk of the work

describes the hardware and software of the constructed instrument in detail, including the prac-

tical obstacles encountered and the solutions adopted. Finally, the performance of the device is

validated through experimental measurements, and its limitations and potential improvements are

discussed [10].

By addressing these objectives, this thesis aims to contribute to the broader effort of making

spectroscopic measurement accessible, transparent, and educationally meaningful — an effort that

is increasingly recognized as valuable not only in chemistry, but in physics education as well [4][5].

## 1 Theoretical Background

### 1.1 Spectroscopy in General

Spectroscopy is the branch of science concerned with the interaction between electromagnetic

radiation and matter. When light encounters a substance, several things can happen: it may be

transmitted, reflected, scattered, or absorbed, depending on the nature of the material and the

wavelength of the radiation. Spectroscopy exploits these interactions to obtain information about

the physical and chemical properties of substances [2]. Different regions of the electromagnetic

spectrum give rise to different types of spectroscopic techniques. X-ray spectroscopy probes the

inner electrons of atoms, infrared spectroscopy reveals molecular vibrations, and UV-visible spec-

troscopy, which is the focus of this work, involves transitions between electronic energy levels [1].

As shown in Figure 1.1, the visible spectrum occupies a narrow band of wavelengths, situated

between the ultraviolet and infrared regions.

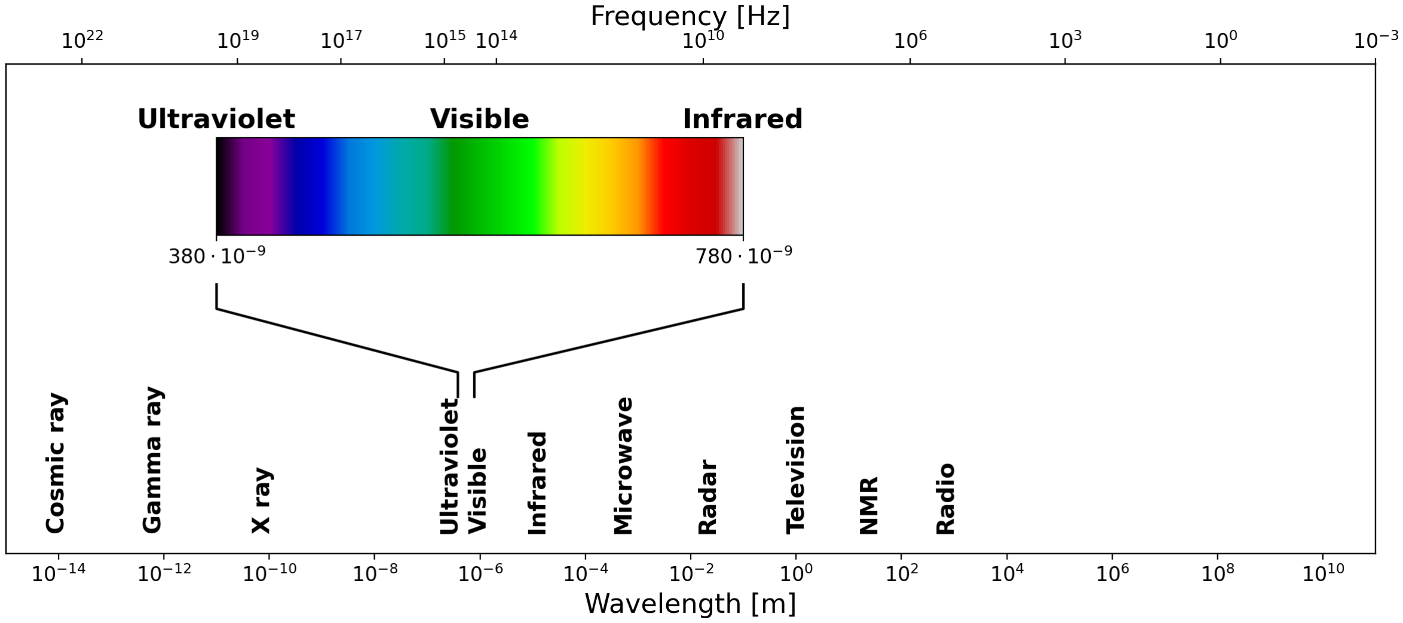
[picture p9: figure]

Figure 1.1: The electromagnetic spectrum, showing the full range of radiation from cosmic rays

to radio waves. The visible region, spanning approximately 380 to 780 nm, is highlighted with its

characteristic color gradient. Both wavelength and frequency scales are shown.

The electromagnetic spectrum spans an enormous range of wavelengths and frequencies, from

very short gamma rays at one extreme to long radio waves at the other. The UV-visible region oc-

cupies only a small portion of this spectrum, roughly from 190 nm to 800 nm, but it is particularly important because the energy of photons in this range corresponds to the energy differences be-

tween electronic states in many molecules. When a photon of the right energy strikes a molecule,

it can be absorbed, promoting an electron from a lower energy level to a higher one. The wave-

lengths at which this absorption occurs are characteristic of the molecular structure, making UV-

visible spectroscopy a powerful tool for both qualitative identification and quantitative analysis of

chemical substances [1][2].

### 1.2 Absorption (UV/Vis) Spectroscopy

The quantitative foundation of absorption spectrophotometry is the Beer-Lambert law, which de-

scribes the relationship between the concentration of an absorbing substance and the amount of

light it absorbs. To understand it, consider a beam of monochromatic light passing through a solu-

tion of an absorbing compound held in a transparent container called a cuvette [10]. Some of the

light will be absorbed by the molecules in solution, and the rest will be transmitted through to the

detector.

The transmittance T of the solution is defined as the ratio of the transmitted light intensity I to

the incident light intensity I0:

T =

I
I0

(1)

Transmittance is often expressed as a percentage. However, for analytical purposes, it is more

convenient to work with the absorbance A, defined as the negative logarithm of the transmittance:

A = −log10(T) = log10
I0
I
(2)

The Beer-Lambert law states that the absorbance is directly proportional to both the concentration

of the absorbing species and the path length of the light through the sample [2]:

A = ε ·l · c | (3)

where ε is the molar absorptivity (also called the molar extinction coefficient), a constant character-

istic of the absorbing substance at a given wavelength, l represents the path length of light through

the sample, as illustrated by the cuvette width in Figure 1.2 (1 cm in standard cuvettes), and c is

the concentration of the absorbing species. The molar absorptivity has units of L mol⁻¹
cm⁻¹
and

can vary enormously between different compounds and different wavelengths [1].

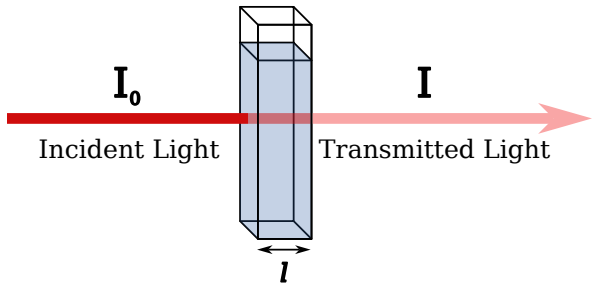
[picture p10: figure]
Incident Light; Transmitted Light

Figure 1.2: Schematic illustration of the Beer-Lambert law. A beam of incident light with intensity

I0 passes through a sample of path length l, emerging with reduced intensity I due to absorption

by the medium.

The Beer-Lambert law is the cornerstone of quantitative spectrophotometry. If the molar ab-

sorptivity of a substance is known, measuring the absorbance of a solution immediately gives its

concentration. In practice, a calibration curve is constructed by plotting the absorbance of stan-

dard solutions against their known concentrations [10], as shown in the right panel of Figure 1.3,

allowing for the determination of unknown sample concentrations via linear interpolation. The

law holds well at low to moderate concentrations, but deviations can occur at high concentrations,

where interactions between molecules begin to affect the absorption behavior, or when the incident

light is not truly monochromatic [1].

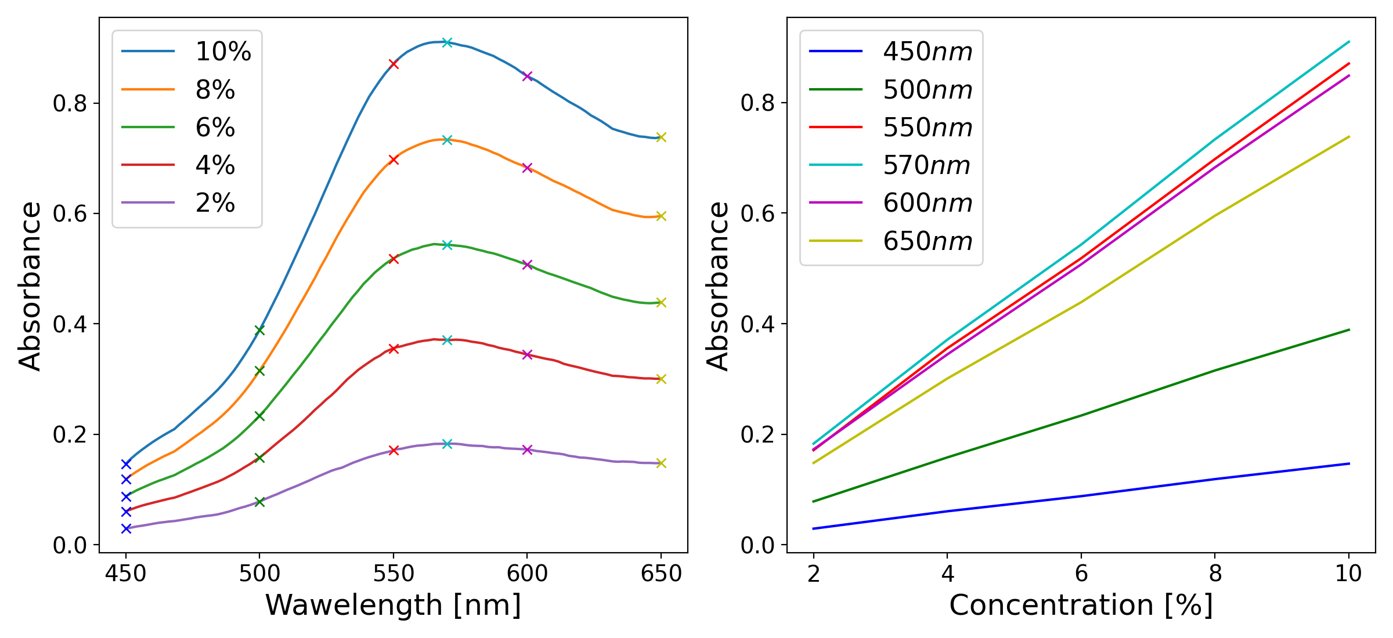
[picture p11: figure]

Figure 1.3: Left: example absorption spectra of a colored solution at five different concentra-

tions, illustrating the characteristic shape of an absorption band and the increase in absorbance

with concentration. Right: absorbance as a function of concentration at six specific wavelengths,

illustrating the linear relationship predicted by the Beer-Lambert law.

### 1.2.1 Absorption Spectra and Molecular Structure

When the absorbance of a substance is measured not just at a single wavelength but across a range

of wavelengths, the result is an absorption spectrum (a plot of absorbance as a function of wave-

length). Each substance has a characteristic absorption spectrum that reflects its molecular struc-

ture, specifically the energies of its electronic transitions. The wavelength at which the absorbance

reaches its maximum is called λmax, and quantitative measurements are most sensitive at this wave-

length, since small changes in concentration cause the largest changes in absorbance [1][10].

The shape and position of absorption bands in the UV-visible spectrum depend on the elec-

tronic structure of the molecule. In organic molecules, the electrons most likely to be involved

in UV-visible absorption are the π electrons in conjugated systems and the non-bonding lone pair

electrons on heteroatoms such as oxygen and nitrogen. As the degree of conjugation in a molecule

increases, the energy gap between the ground state and the excited state decreases, and the absorp-

tion band shifts to longer wavelengths: a phenomenon known as a bathochromic or red shift. This

is why, for example, beta-carotene, which has a long conjugated chain, absorbs strongly in the

visible region and appears orange, while simpler molecules with fewer conjugated bonds absorb

in the UV and are colorless [1][10].

### 1.2.2 Structure and Operation of Absorption Spectrometers

A UV-visible absorption spectrophotometer is an instrument designed to measure the absorbance

of a sample as a function of wavelength. Despite the many variations in design and complexity

that exist, all spectrophotometers share the same fundamental architecture, consisting of five basic

components: a light source, a wavelength selector, a sample holder, a detector, and a readout

system [1]. The spatial arrangement and theoretical operation of the primary optical components

are schematically represented in Figure 1.4, with the readout system typically integrated into a

modern computer interface.

## Light

Source | Detector

## Monochromator

Figure 1.4: Block diagram of the fundamental components of a single-beam absorption spec-

trophotometer.

The light source must emit radiation across the entire wavelength range of interest with suffi-

cient and stable intensity. For UV-visible spectrophotometry, two types of lamps are commonly

used in commercial instruments: a deuterium lamp, which provides continuous radiation in the

UV region (190–400 nm), and a tungsten-halogen lamp, which covers the visible and near-infrared

region (350–900 nm). Many instruments automatically switch between the two lamps as the wave-

length scan crosses the boundary between the UV and visible regions. In lower-cost and educa-

tional instruments, white LEDs are a popular alternative, as they are inexpensive, energy-efficient,

and emit across much of the visible range, though with a non-uniform spectral output [1][4].

The wavelength selector is the component responsible for isolating a narrow band of wave-

lengths from the broadband output of the light source. In modern spectrophotometers, this is

almost always achieved using a diffraction grating (a flat optical surface ruled with a large number

of closely spaced parallel grooves). The diffraction grating spatially separates the incident light,

directing different wavelengths into different angles according to the grating equation:

nλ = d sinθ | (4)

where n is the diffraction order (typically 1), λ is the wavelength of the diffracted light, d is

the spacing between adjacent grooves, and θ is the diffraction angle. By rotating the grating or

scanning the detector angle, different wavelengths can be directed onto the sample in sequence,

allowing a full spectrum to be recorded. Older instruments used prisms as dispersive elements, but

gratings have largely replaced them due to their more linear dispersion and lower cost [1].

The sample holder is typically a cuvette — a small transparent container with a precisely de-

fined path length, usually 1 cm. Cuvettes for UV measurements must be made from materials

that do not absorb UV radiation, such as quartz or fused silica. For measurements confined to the

visible region, less expensive plastic or glass cuvettes are perfectly adequate [1].

The detector converts the transmitted light intensity into an electrical signal. The most common

detector type in modern instruments is the photodiode, which generates a current proportional to

the incident light intensity. In instruments designed to record a full spectrum simultaneously, an

array of photodiodes (known as a photodiode array or PDA) can be used, replacing the need to scan

through wavelengths mechanically. Photomultiplier tubes (PMTs), which offer much higher sensi-

tivity, are used in high-end research instruments. For educational and low-cost devices, simpler de-

tectors such as light-dependent resistors (LDRs) or phototransistors are also viable options [1][4].

Finally, the readout system processes the electrical signal from the detector and presents the re-

sult to the user. In modern instruments this is handled entirely by software running on a connected computer, which can display the spectrum, perform baseline corrections, and carry out quanti-

tative calculations automatically. In simpler home-built instruments, the detector signal is often

read directly with a digital multimeter and the absorbance calculated by hand or with a simple

script [1][8].

It is worth noting the distinction between single-beam and double-beam instrument designs.

In a single-beam spectrophotometer, the sample and the blank (a reference solution, typically the

pure solvent) are measured sequentially, and the ratio of their signals gives the transmittance.

In a double-beam instrument, the light is split into two paths (one through the sample and one

through the reference) and both are measured simultaneously. The double-beam design is more

stable against fluctuations in the light source intensity and is therefore preferred in research-grade

instruments, although single-beam designs are perfectly adequate for many educational and routine

analytical applications [1][2].

## 2 Review of Low-Cost / DIY Spectrophotometers

The development of low-cost and home-built spectrophotometers has been an active area of in-

terest in the educational and scientific community for several decades. The motivations behind

these efforts are clear: commercial instruments are often prohibitively expensive for schools and

smaller institutions, and even when available, they offer little insight into the physical principles of

the measurement. A wide variety of designs have been proposed over the years, differing in com-

plexity, cost, target audience, and performance. This section reviews the most relevant examples

from the literature, with particular attention to the design choices made and the lessons that can be

drawn for the present work.

One of the earliest and most accessible designs is that described by Lema et al. [6], who built

a spectrophotometer from components readily available to anyone: a halogen flashlight as the

light source, a compact disc (CD) as the diffraction element, a light-dependent resistor (LDR) as

the detector, and a standard digital multimeter for readout. The entire assembly was mounted in a

cardboard box, with two simple slits used to collimate the diffracted light onto the detector. Despite

its extreme simplicity, this device was capable of producing recognizable absorption spectra and

calibration curves for several biochemically relevant substances, including chlorophyll, starch,

and proteins. The authors demonstrated its use in a series of teaching experiments in a biosciences

course, showing that meaningful quantitative results could be obtained even with such minimal

means. The main limitation of this design is its poor wavelength resolution (rotating the CD by

a single degree corresponds to a wavelength change of approximately 25 nm) and the fact that

it provides resistance readings rather than direct absorbance values. Nevertheless, it remains a

compelling demonstration of how far ingenuity can go in replacing expensive equipment [6].

A more structured approach was taken by Knagge and Raftery [7], who designed a LEGO-

based spectrophotometer for use in a graduate-level chemical instrumentation course at Purdue

University. Their instrument incorporated a miniature filament lamp as the light source, a convex

lens and an infrared filter for light conditioning, a 1000 lines/mm transmission diffraction grating,

a spring-loaded rotating mirror for wavelength selection, a silicon photodetector, and an amplifier

circuit connected to a digital multimeter. The use of LEGO bricks as optical mounts was motivated

by their precise manufacturing tolerances, modularity, and mechanical stability, which make them

well suited to holding optical components in alignment. The instrument achieved a wavelength

resolution of approximately 8 nm and was used to record absorption spectra and calibration curves

for potassium permanganate. Compared to a commercial Spectronic 20 instrument, the home-built device showed higher stray light levels and a higher limit of detection, but its calibration curves

displayed similar linearity. The total cost was approximately 200 USD. The authors emphasized

that the educational value of the device lay not only in its use, but in the process of construction

itself, through which students gained practical experience with the optical and electronic modules

that make up any analytical instrument [7].

Building on the LEGO concept but targeting a much younger and less specialized audience, Al-

bert, Todt, and Davis [8] developed a significantly simpler and cheaper LEGO spectrophotometer

designed for use in high school physics and chemistry classes. Their design used a white LED as

the light source, a single lens for collimation, a 1000 lines/mm slide-mounted diffraction grating,

and a photodiode mounted on a rotatable arm for wavelength selection, with a digital multimeter

as the readout. The entire apparatus was built on a standard LEGO baseplate and could be as-

sembled and optimized in approximately 45 minutes. The total cost was around 25 USD, roughly

one eighth of the cost of the Knagge and Raftery design. Despite its simplicity, the device pro-

duced absorbance measurements in close agreement with those from a commercial Ocean Optics

USB2000+ spectrophotometer over the typical working range of absorbance values up to about

1, and was capable of recording full visible absorption spectra between approximately 420 and

660 nm. The authors noted that the use of familiar toy materials made the activity engaging for

students, and that the transparent design effectively exposed the physical principles that are hidden

in commercial black-box instruments [8].

A very different approach is represented by the work of Wang et al. [9], who demonstrated

a smartphone-based spectrometer for colorimetric biosensing applications. Their device used the

built-in LED flash of a smartphone as the light source, a compact disc fragment as the diffraction

grating, and the smartphone’s CMOS camera as the detector. The entire optical assembly was com-

pact and required no external components beyond a simple sample cell. The smartphone camera

captured the dispersed spectrum as an image, which was then processed using a dedicated Android

application to extract the absorbance spectrum. The device was tested for the detection of glucose

using an enzymatic colorimetric assay and for the detection of cardiac troponin I using peptide-

functionalized gold nanoparticles, achieving limits of detection comparable to those of commercial

bench-top instruments. While this design is more oriented toward portable point-of-care diagnos-

tics than classroom education, it illustrates the remarkable potential of consumer electronics as

spectroscopic platforms, and it highlights the growing role of smartphones and digital cameras as

detectors in low-cost spectrophotometry [9].

González-Morales et al. [3] presented a portable low-cost UV-Vis spectrophotometer specifi-

cally designed for field measurements of environmental contaminants, with a particular application to the detection of mercury ions in water using a synthesized chemosensor. Their instrument op-

erated in the visible range from 400 to 700 nm and used a 1 W white LED as the light source, a

DVD-derived diffraction grating mounted on a stepper motor for automated wavelength scanning,

and a TEMT6000 phototransistor as the detector. The entire device was housed in a 3D-printed

black enclosure and controlled by an Arduino microcontroller, which performed the wavelength

sweep, acquired the detector signal, computed the absorbance, and transmitted the data to a com-

puter. Two independent sample chambers allowed simultaneous measurement of the sample and a

reference, improving stability. The total cost of the device was below 86 USD. Absorbance mea-

surements agreed with those from a commercial Cary 60 spectrophotometer with error percentages

below 10% for most concentrations, and below 5% for the mercury detection experiments. This

design is particularly noteworthy for its level of integration and automation, demonstrating that a

microcontroller-based instrument can approach commercial performance at a small fraction of the

cost [3].

Finally, the Viking spectrophotometer developed by Kolesnichenko et al. [5] represents one

of the most pedagogically sophisticated examples in the recent literature. Rather than aiming for

maximum analytical performance, this design prioritized the learning experience above all else.

The instrument was built from wooden holders, inexpensive magnifying glass lenses, a white LED

light source with a replaceable aluminum foil slit, and a transmission diffraction grating mounted

in a slide frame. Crucially, no fixed housing was used, all components were freely positioned on

a flat table, allowing students to experiment with different configurations, observe the effects of

misalignment, and develop genuine physical intuition. The spectrum was projected onto a white

cardboard screen and photographed with a smartphone camera for digitization. The device sup-

ported both absorption and fluorescence measurements and was successfully deployed across a

wide range of educational levels, from high school outreach activities to Master and PhD level

courses at Lund University. Its total material cost was approximately 14 euros per set. The authors

reported that engagement with the Viking spectrophotometer measurably improved the quality of

students’ laboratory reports and their confidence when subsequently operating professional instru-

ments [5].

Taken together, these examples illustrate that low cost and high educational value are not mu-

tually exclusive, and that the integration of a microcontroller with dedicated software can dramat-

ically extend the functionality of a home-built device without greatly increasing its cost. These

considerations have directly shaped the design decisions described in the following chapter.

## 3 Design and Implementation of the Spectrophotometer

### 3.1 Hardware

### 3.1.1 Idea

The starting point for the hardware design was the desire to build a functional absorption spec-

trophotometer that was as simple and inexpensive as possible, while remaining open to future

refinement and improvement. A key decision in this direction was the choice of the SparkFun

AS7262 (https://cdn.sparkfun.com/assets/f/b/c/c/f/AS7262.pdf) Visible Spectral Sensor as the core detection element. This sensor measures light inten-

sity in six fixed channels across the visible spectrum, centered at 450, 500, 550, 570, 600, and

650 nm, and communicates digitally with a microcontroller via I2C. Its main advantage for this

application is that it eliminates the need for a diffraction grating and a rotating wavelength selector

entirely, the spectral discrimination is handled internally by the sensor itself. This greatly sim-

plifies the optical layout and reduces the number of precision components required, at the cost of

spectral resolution, since the instrument can only sample six discrete wavelengths rather than a

continuous spectrum.

As the microcontroller, an Arduino Uno (https://docs.arduino.cc/resources/datasheets/A000066-datasheet.pdf) was chosen. This is a natural pairing with the AS7262

sensor, as the Arduino provides the I2C interface needed to communicate with it, can supply the

sensor with power, and can transfer the acquired data to a PC via its USB connection. The Arduino

Uno is also widely available, inexpensive, and well documented, making it a suitable platform for

an educational instrument.

For the light source, an incandescent bulb was preferred over an LED. While LEDs are cheaper

and more energy efficient, their emission spectrum is strongly peaked at specific wavelengths,

which can result in uneven illumination across the six detection channels of the sensor. An in-

candescent bulb, by contrast, emits a broad and relatively smooth blackbody-like spectrum across

the entire visible range, providing more uniform illumination of all channels. The chosen bulb is

a Goobay product with an E10 socket, rated at 3.5 V and 0.2 A, giving a power consumption of

0.7 W. This low current draw is important, as the 5V power pin of the Arduino Uno can supply a

limited current, and exceeding it risks damaging the board.

The optical layout follows a straightforward single-beam transmission configuration. Light

from the bulb passes through a vertical slit, which collimates it into a narrow beam. This beam then

passes through the cuvette, which holds the sample solution. A second slit placed after the cuvette further restricts the beam before it reaches the AS7262 sensor. Standard commercial cuvettes with

a 10×10 mm inner cross section and 1 cm path length were used, consistent with the standard

path length assumed in Beer-Lambert law calculations. The structural frame holding all of these

components together was designed in 3D modeling software and printed using a high-precision

3D printer with PLA filament, resulting in a compact enclosure slightly smaller than a 6×10×25

cm block. The detailed plans (and software files) can be found in the GitHub repository: https:

//github.com/bacstamas/Spectrometer_2026.

### 3.1.2 Obstacles

The development of the hardware went through two main iterations, driven by a series of practical

problems encountered during testing.

The first version of the frame was modular in design, meaning that the positions of the light

source, the slits, and the sensor could be adjusted along the optical axis. This was useful in the

early stages of development, as it allowed the optimal spacing between components to be found

experimentally. However, this first version had no cover or enclosure around the optical path,

meaning that ambient light from the room could reach the sensor and contaminate the measure-

ments. As a result, all measurements with this version had to be performed in a darkened room,

which was clearly impractical for regular use.

A further issue that emerged during testing was the need to control the intensity of the light

source. The AS7262 sensor has a fixed integration time and gain setting for each measurement,

and if the light reaching it is too intense, the sensor saturates and the readings become unreliable.

A way to reduce the light intensity without modifying the optical layout was therefore needed.

Finally, the PLA filament used for 3D printing presented an unexpected problem. The filament

available was blue in color, and it turned out to be partially translucent to ambient light, allowing

a non-negligible amount of stray light to penetrate the walls of the enclosure even in the second,

closed version of the frame.

### 3.1.3 Implementation

The second version of the frame addressed the problems identified during testing with the first.

All components (the light source, the two slits, the cuvette holder, and the sensor) were given

fixed, precisely dimensioned positions inside a closed enclosure, based on the optimal spacing

determined during the first phase. The enclosure included a removable cover to allow access

to the cuvette holder for changing samples, while keeping the rest of the optical path shielded from ambient light. A dedicated bay was also added to securely mount the Arduino Uno board,

positioned with the USB Type-B connector accessible from the outside of the enclosure, so that

the connection to the PC could be made without opening the instrument. Crucially, the Arduino

was physically separated from the optical components inside the box, so that the indicator LEDs

on the board would not interfere with the sensor readings. The internal structure of the assembled

spectrometer is shown in Figure 3.2.

To solve the problem of stray light penetrating through the blue PLA walls, the exterior and

interior surfaces of the enclosure were painted with a matte black paint of the type used industri-

ally to produce surfaces with near-unity emissivity for thermal imaging applications. This paint

effectively blocked the residual light transmission through the plastic walls and also minimized

internal reflections within the enclosure.

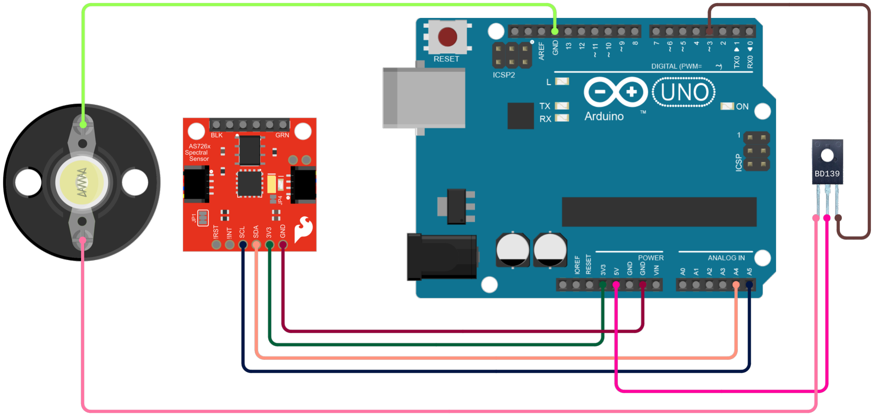
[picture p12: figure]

Figure 3.1: Circuit diagram of the spectrophotometer electronics, showing the connections be-

tween the Arduino Uno, the SparkFun AS7262 spectral sensor (I2C interface), the BD139 NPN

transistor, and the incandescent light bulb. The transistor is driven by the PWM output on pin 3 of

the Arduino and controls the current through the light source.

The light intensity control problem was solved by adding a BD139 (https://share.google/5DOaTHuip5NTmbAFO) NPN bipolar transistor to

the circuit. The transistor was wired with its collector connected to the Arduino’s 5V supply pin,

its emitter connected to the positive terminal of the light bulb, and the negative terminal of the bulb

connected to the Arduino’s ground. The base of the transistor was driven by pin 3 of the Arduino,

which is a PWM-capable output. By varying the duty cycle of the PWM signal, the effective voltage across the bulb can be adjusted continuously, allowing the light intensity to be tuned to

a level that keeps the sensor within its linear operating range without saturating it. This simple

addition significantly improved the reliability and reproducibility of the measurements. See Figure

3.1 for the circuit diagram.

Several sub-components, including the sensor holder, the cuvette holder, and the box cover,

went through additional minor refinements beyond the two main frame iterations, as small geo-

metric adjustments were needed to improve the fit and reduce stray light leakage around the edges.

The final assembled instrument is a compact, self-contained device that can be connected to any

computer via a standard USB cable and operated without any need for a darkened environment.


Figure 3.2: Photo of the inside of the spectrometer.

### 3.2 Software

The software component of the spectrophotometer system consists of two separate programs: the

firmware running on the Arduino microcontroller, which is responsible for directly operating the sensor and acquiring data, and a Java desktop application running on the PC, which serves as the

interface between the user and the instrument. The two communicate through a serial connection

over USB.

The Arduino firmware is intentionally kept simple and lightweight. On startup, it initializes

the AS7262 sensor and sets a default configuration for the measurement parameters. It then enters

a waiting loop, listening for commands arriving through the serial port.

When a measurement is requested, the command arrives as a formatted string specifying all

relevant parameters: integration time, gain, number of averages, measurement mode, and light

intensity. The firmware parses this string, applies the specified settings to the sensor, and adjusts the

PWM signal on pin 3 to set the light source intensity accordingly. It then performs the measurement

the requested number of times and computes the average across repetitions for each of the six

spectral channels. The result is sent back to the PC as a single comma-separated line of six floating

point values, one per channel.

The AS7262 sensor library supports two measurement modes: a raw mode, which returns the

unprocessed digital counts from each photodetector channel, and a calibrated mode, which applies

internal corrections to return values in units of calibrated irradiance. Both modes are accessible

through the firmware and can be selected by the user from the PC software.

The PC-side software is written in Java, a choice motivated by several practical considerations.

Java is inherently cross-platform, the same application can run on Linux, Windows, and macOS

without significant modification, and it lends itself naturally to well-structured, object-oriented

design that can be extended and maintained over time. The application was developed and tested

on Linux but is intended to be portable across operating systems. It uses the jSerialComm library

for serial port communication, the XChart library for data visualization and the Jackson library for

handling JSON files.

The architecture of the application is organized around a small set of well-defined classes, each

with a clear responsibility. This separation of concerns makes the codebase easy to navigate and

extend without requiring a complete redesign.

### 3.2.1 Structure

The Spectrometer class is the core of the application. It is responsible for all communication with

the Arduino hardware. On instantiation, it automatically scans the available serial ports on the

system (using the jSerialComm library) and identifies the connected Arduino by checking port de-

scriptors and system names. Once connected, it configures the serial port parameters (baud rate, data bits, stop bits, parity) opens the connection, and flushes any startup messages sent by the

Arduino. It exposes methods to configure the measurement parameters and to trigger measure-

ments, handling the sending of the formatted command string and the reception and parsing of the

response. Each call to the measurement method can request multiple spectra in sequence, each

acquired with on-board averaging by the Arduino.

The MeasurementSet class acts as a container for all data associated with a single acquisition

session. It stores the list of individual spectra recorded during that session, the full set of mea-

surement parameters used, and a unique name composed of a user-defined label and the date and

time of acquisition. It provides methods for computing the mean and standard deviation across

the recorded spectra for each channel, for formatting this information as a readable string, and for

saving the entire measurement set to a JSON file or loading it back from one. JSON format was

chosen because it is human-readable and easy to handle.

The Visualizer class handles all data visualization. It takes a MeasurementSet as input and can

produce two types of charts: a spectrum plot showing the intensity values across the six channels of

the sensor, and an absorption spectrum computed from two separate measurement sets representing

the reference and the sample. The absorbance at each channel is calculated according to the Beer-

Lambert law as:
A = −log10
Isample

Ire f erence
(5)

where Isample and Ire f erence are the mean intensities of the sample and reference measurements at

each channel respectively. The Visualizer class uses the XChart library to produce the actual chart

objects, which are then embedded in the GUI.

The remaining classes handle the graphical user interface. The Main class serves as the applica-

tion entry point, launching the GUI on the appropriate thread. The MainWindow class implements

the main application window, while the remaining classes manage the panels, menus, and dialogs,

and handle specific user interactions.

### 3.2.2 Features

The main window of the application is organized around a central list that displays all measure-

ment sets currently loaded in memory, each identified by its unique name. From the main window,

the user can connect to the spectrometer and configure the measurement parameters through a ded-

icated dialog, which provides input fields for integration time, gain, number of averages, number

of measurements, measurement mode, and light intensity. Once configured, a measurement can be

triggered with a single button press. The acquired measurement set is automatically added to the list and displayed in a text area showing its parameters and statistics.

Measurement sets can be saved to and loaded from plain text files, allowing results to be stored

for later analysis or shared between sessions. The user can also load previously saved measure-

ments without connecting to the hardware, making it possible to perform data analysis and visual-

ization independently of the instrument.

For visualization, two separate plot types are available. The spectrum plot displays the raw or

calibrated intensity values across the six sensor channels for a selected measurement set, while the

absorption plot computes and displays the absorbance spectrum from a user-selected reference and

sample pair. Both plot types offer configurable options accessible through dialog windows: the

x-axis can be displayed in wavelength (nm) or in frequency (THz), the y-axis values can be shown

as raw values or normalized to the maximum, the plot style can be switched between a line curve

and a bar chart, and error bars representing the standard deviation across repeated measurements

can be toggled on or off.

### 3.2.3 Data Processing and Calibration

The data processing performed by the software is deliberately straightforward, reflecting the edu-

cational purpose of the instrument. The primary computation is the averaging of repeated spectra,

which is handled partly by the Arduino firmware, which averages multiple sensor readings within a

single acquisition, and partly by the MeasurementSet class, which computes the mean and standard

deviation across multiple sequential acquisitions requested by the user. This two-level averaging

scheme gives the user flexibility in balancing measurement speed against statistical reliability.

The absorbance calculation follows directly from the Beer-Lambert law, as described above.

No additional baseline correction or spectral smoothing is applied, keeping the processing chain

transparent and easy to follow.

### 3.3 Experimental Results and Validation

With the hardware and software components completed, a series of experiments was carried out

to characterize the performance of the instrument and to validate its suitability for quantitative

absorbance measurements.

### 3.3.1 Stray Light Test

The first test performed was aimed at verifying that the closed enclosure of the spectrophotometer

effectively excludes ambient light. An empty cuvette was placed in the cuvette holder, the cover

of the box was closed, and the light source intensity was set to 0, meaning the bulb was switched

off via the PWM control. Under these conditions, repeated measurements returned a value of

exactly zero on each of the six channels of the sensor. This result confirms that no stray or ambient

light reaches the detector when the light source is off, validating the effectiveness of the matte

black coating applied to the interior of the enclosure and ruling out the presence of any light leaks

through the housing.

### 3.3.2 Reproducibility Test

To assess the reproducibility of the measurements, a solution of yellow food coloring at a concen-

tration of 2.5% was prepared and measured repeatedly. Ten independent measurement sets were

acquired, each consisting of 100 individual measurements per channel (integration time: 100 ms,

gain: 16, averaging: 1, mode: raw, light intensity: 100). All ten sets were plotted together, as

shown in Figure 3.3, where each of the six channels is represented by ten overlapping traces of

100 points each.


Figure 3.3: Raw measurement values recorded across the six channels of the AS7262 sensor (450,

500, 550, 570, 600, and 650 nm) for ten independently acquired measurement sets of a 2.5%

yellow food coloring solution, each consisting of 100 individual measurements.

The plot shows that the measured values remain clustered around a stable baseline for each

channel, with some random scatter present throughout the dataset. Averaging across all 1000

individual measurements per channel (10 sets × 100 measurements), the mean raw values obtained

were {3.99,14.251,33.428,50.629,11.336,24.334} for the 450, 500, 550, 570, 600, and 650 nm

channels respectively, with corresponding standard deviations of {0.099, 0.522, 1.101, 2.004,

0.501, 0.696}. The relative standard deviation remains below approximately 4% for every channel,

which indicates a satisfactory level of reproducibility for an instrument of this cost and complexity.

This noise may be attributable to small imperfections such as scratches on the cuvette surface and

slight variations in its exact positioning within the holder between insertions.

### 3.3.3 Long-Term Stability Test

A further test was conducted to check whether the solution itself remained stable over time, an im-

portant consideration since sedimentation or settling of the food coloring could introduce a system-

atic drift in absorbance unrelated to the instrument’s performance. The same yellow food coloring

solution and the same measurement parameters used in the reproducibility test were employed. A cuvette containing the solution was measured once, left undisturbed inside the instrument for 24

hours, and then measured again without being touched or repositioned in between. The differ-

ence between the two measurements was found to be smaller than the standard deviations already

observed in the reproducibility test, indicating that no significant settling or degradation of the

solution occurred over this timescale, and that any short-term drift in the instrument’s readings is

dominated by the handling-related noise identified above rather than by sample instability.

### 3.3.4 Calibration Curves

Finally, the linearity of the instrument’s response was tested by preparing a series of yellow food

coloring solutions at concentrations ranging from 0.8% to 10%, and measuring the absorbance

of each at all six sensor channels. The resulting calibration curves are shown in Figure 3.4 (one

subplot for each channel) together with a linear best-fit line.

Across all six channels, the measured absorbance values follow the linear trend predicted by the

Beer-Lambert law reasonably well, particularly in the central concentration range. Some scatter

around the fitted line is visible, which is consistent with the absolute measurement noise identi-

fied in the reproducibility test. The channels at 550, 570, and 600 nm, which are closer to the

absorption maximum of the yellow dye, display the clearest linear behavior and the largest overall

absorbance range, while the 450 nm channel, which lies further from the absorption peak, shows

comparatively more scatter relative to its smaller dynamic range. Overall, these results confirm

that the constructed instrument is capable of producing calibration curves with a clearly recogniz-

able linear character across the entire visible range covered by the sensor, supporting its intended

use for quantitative concentration measurements in an educational context.


Figure 3.4: Six calibration curves showing absorbance against concentration (%), along with their

corresponding best-fit lines, at each of the sensor’s wavelengths.

## Conclusion

The primary objective of this thesis was the design, construction, and validation of a low-cost

absorption spectrophotometer intended for educational use. The developed instrument combines

simple hardware with dedicated software for data acquisition, visualization, and absorbance cal-

culation. Experimental testing demonstrated that the spectrometer is capable of producing repro-

ducible measurements and calibration curves that follow the linear behavior predicted by the Beer-

Lambert law. While the measurements exhibit a non-negligible level of noise, the results show that

the instrument is sufficiently reliable for educational and demonstration purposes, provided that

appropriate care is taken during sample preparation and measurement.

One of the main strengths of the instrument is its combination of low cost and transparency.

Unlike commercial spectrophotometers, whose internal operation is often hidden from the user,

the present design exposes the essential elements of an absorption measurement system and makes

the underlying physical principles easier to understand. As a result, the spectrometer is well suited

for use in secondary-school and undergraduate laboratory activities. Students can gain practi-

cal experience with solution preparation, reference measurements, absorbance calculations, the

construction of calibration curves, and the quantitative determination of concentrations. More ad-

vanced educational projects could even include the determination of the molar absorptivity of a

substance through Beer-Lambert analysis.

Beyond its use as a measurement instrument, the reproduction of the spectrometer itself could

serve as a valuable educational project for physics students at the BSc or MSc level. Constructing

the device requires engagement with several important areas of modern scientific and engineering

practice, including absorption spectroscopy, 3D design and printing, microcontroller program-

ming, object-oriented software development, and experimental testing. The process of building

and validating the instrument provides a deeper understanding of both the physical principles and

the practical challenges involved in spectroscopic measurements.

Although the instrument successfully fulfills its intended educational purpose, several opportu-

nities for further development remain. One possible improvement would be the replacement of the

AS7262 sensor with a sensor offering a larger number of spectral channels, increasing the spectral

resolution of the measurements. Another possibility would be to adopt a more traditional spec-

trometer architecture based on a rotatable diffraction grating and a simpler photodetector, allowing

the acquisition of a continuous spectrum rather than measurements at six discrete wavelengths.

Such modifications could improve the analytical capabilities of the instrument while preserving its

educational value.

A particularly promising direction for future development would be the replacement of the

Arduino Uno with an ESP32 microcontroller. The additional processing power and built-in Wi-

Fi connectivity of the ESP32 would make it possible to implement the user interface as a web

application hosted directly by the instrument. In such a design, users could access the spectrometer

through any device equipped with a web browser, without the need to install dedicated software.

This would simplify deployment in classroom environments, reduce platform-dependence, and

further increase the accessibility of the system.

In conclusion, the developed spectrophotometer demonstrates that quantitative absorption mea-

surements can be achieved with inexpensive and widely available components. Although it cannot

compete with commercial instruments in terms of precision or spectral resolution, it successfully

fulfills its intended role as an educational tool and provides a practical platform for teaching both

spectroscopy and scientific instrumentation.

## References

[1] OWEN, Tony. Fundamentals of UV-visible spectroscopy. 2000.
[2] Demystifying spectroscopic analysis through expert insights and practical resources: www.

spectroanalysis.com

[3] GONZÁLEZ-MORALES, David, et al. Development of a low-cost UV-Vis spectrophotome-

ter and its application for the detection of mercuric ions assisted by chemosensors. Sensors,

2020, 20.3: 906.

[4] KOVARIK, Michelle L.; CLAPIS, Julia R.; ROMANO-PRINGLE, K. Ana. Review of

student-built spectroscopy instrumentation projects. Journal of Chemical Education, 2020,

97.8: 2185-2195.

[5] KOLESNICHENKO, Pavel V., et al. Viking spectrophotometer: a home-built, simple, and

cost-efficient absorption and fluorescence spectrophotometer for education in chemistry.

Journal of Chemical Education, 2023, 100.3: 1128-1137.

[6] LEMA, Martín A.; ALJINOVIC, Ernesto M.; LOZANO, Mario E. Using a homemade

spectrophotometer in teaching biosciences. Biochemistry and Molecular Biology Education,

2002, 30.2: 106-110.

[7] KNAGGE, Kevin; RAFTERY, Daniel. Construction and evaluation of a LEGO spectropho-

tometer for student use. The Chemical Educator, 2002, 7.6: 371-375.

[8] ALBERT, Daniel R.; TODT, Michael A.; DAVIS, H. Floyd. A low-cost quantitative absorp-

tion spectrophotometer. Journal of Chemical Education, 2012, 89.11: 1432-1435.

[9] WANG, Yi, et al. Smartphone spectrometer for colorimetric biosensing. Analyst, 2016,

141.11: 3233-3238.

[10] Advancing analytical chemistry knowledge through expert insights and research.: www.

analchemsci.com

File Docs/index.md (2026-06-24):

# Introduction and Objectives

Since vision is one of our most important and highly developed senses, it is natural that humans have long sought to build instruments capable of performing similar tasks in a quantitative and objective manner. Just as the human eye can often provide a qualitative impression of whether a sample of water is clean or contaminated, a spectrophotometer can analyze the interaction of light with matter and provide quantitative information about the composition and concentration of substances dissolved in a solution. This is widely used in chemistry, biology, medicine, and environmental monitoring. In particular, UV-visible (UV-Vis) absorption spectrophotometry is built on the Beer-Lambert law, which states that the amount of light absorbed by a solution is proportional to the concentration of the absorbing substance. This makes it an indispensable tool in both research and educational settings, where it underlies experiments ranging from the quantification of biomolecules to the study of reaction kinetics [[1]](bibliography.md#ref1)[[2]](bibliography.md#ref2).

Despite its importance, access to absorption spectrophotometry is far from universal. Commercial UV-Vis spectrophotometers, while offering excellent performance, are expensive instruments that many schools and universities, particularly those with limited budgets, cannot afford [[3]](bibliography.md#ref3). Beyond the financial barrier, modern commercial instruments present a further challenge in educational contexts: they function as so-called "black boxes", hiding from the user the physical principles that underlie the measurement. Students who interact only with polished commercial devices are often left with little understanding of how a spectrum is actually generated, what role the diffraction grating plays, or why alignment and calibration matter [[4]](bibliography.md#ref4)[[5]](bibliography.md#ref5). This gap between instrument use and instrument understanding is a genuine obstacle to deep learning in physics and chemistry education.
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

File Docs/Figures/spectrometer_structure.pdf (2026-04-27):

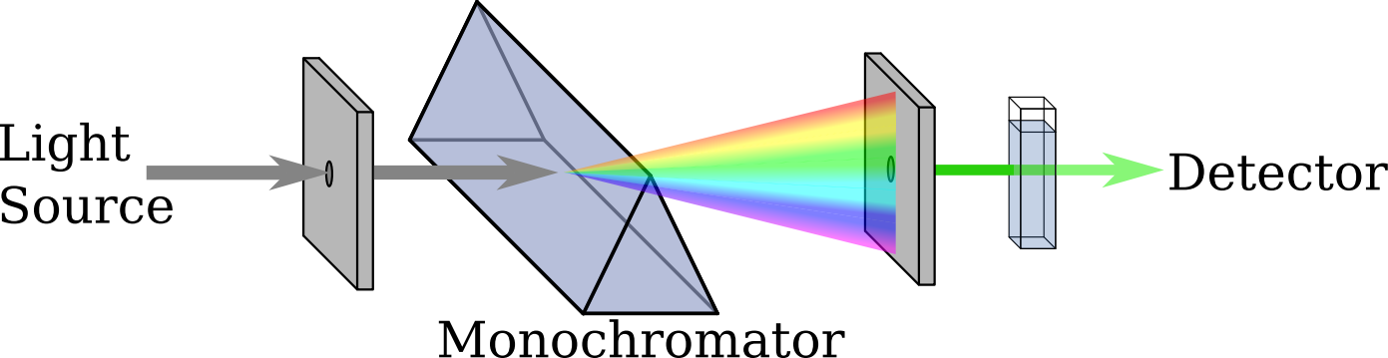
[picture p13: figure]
Light; Source; Detector; Monochromator
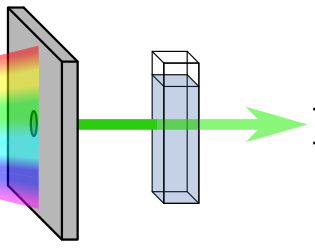
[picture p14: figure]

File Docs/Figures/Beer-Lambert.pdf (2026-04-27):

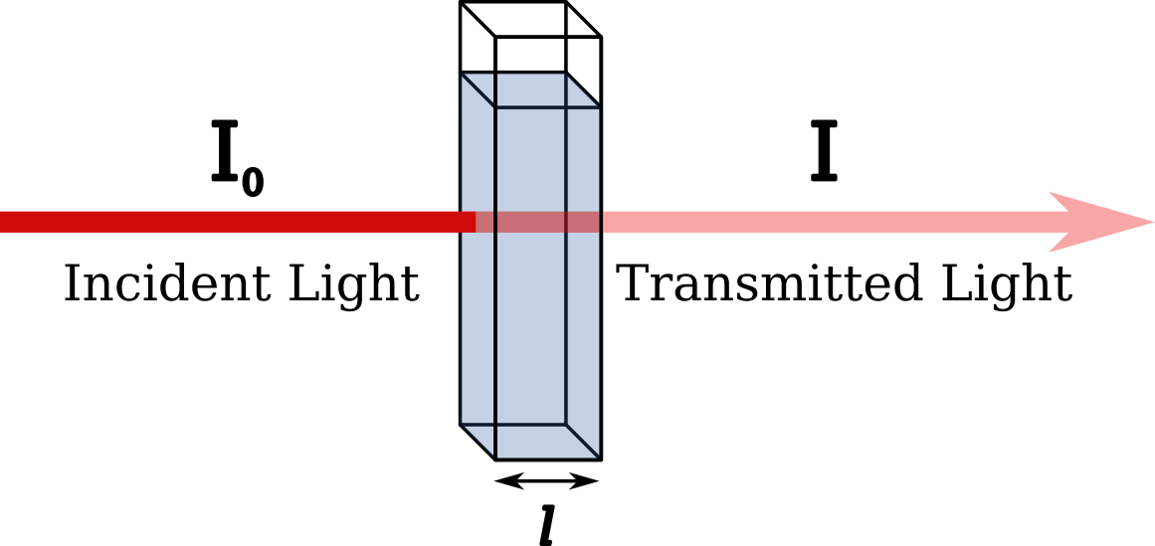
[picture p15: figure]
Incident Light; Transmitted Light

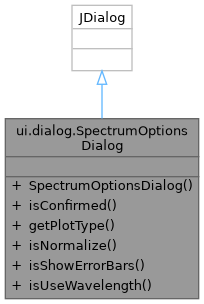
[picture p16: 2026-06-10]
Docs/html/classui_1_1dialog_1_1SpectrumOptionsDialog__coll__graph.png

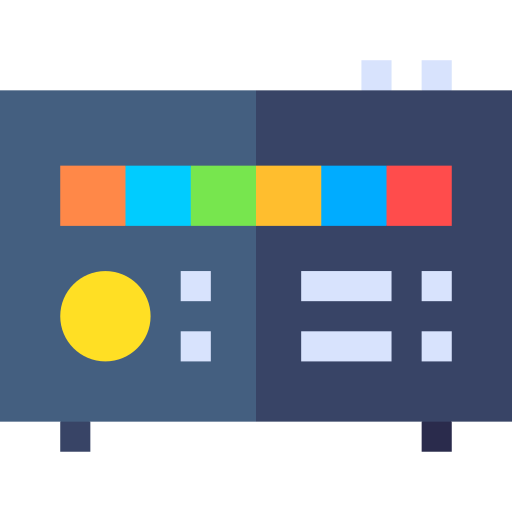
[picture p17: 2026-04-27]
Docs/Figures/spectro.png

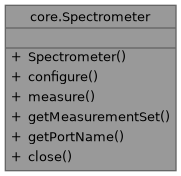
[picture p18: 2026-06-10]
Docs/html/classcore_1_1Spectrometer__coll__graph.png

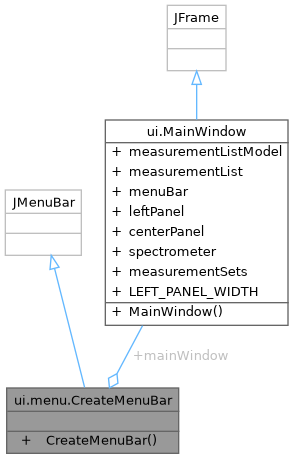
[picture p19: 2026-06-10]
Docs/html/classui_1_1menu_1_1CreateMenuBar__coll__graph.png

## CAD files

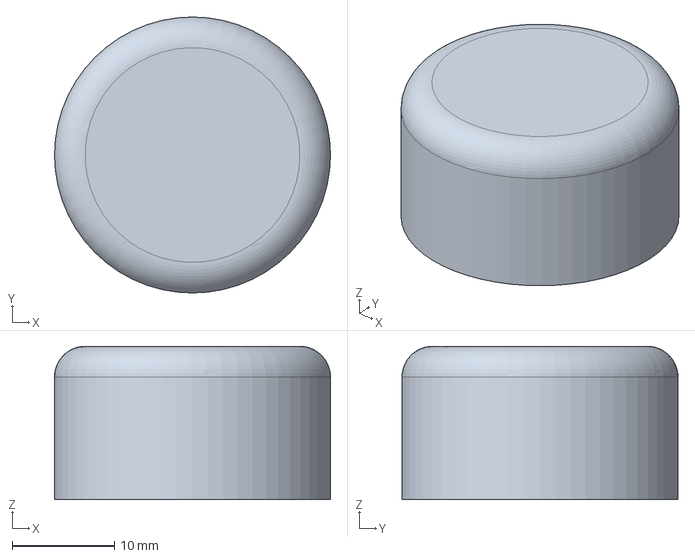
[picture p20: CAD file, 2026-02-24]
3DModels/FreeCAD/cap.FCStd
27.0 x 27.0 x 15.0 mm

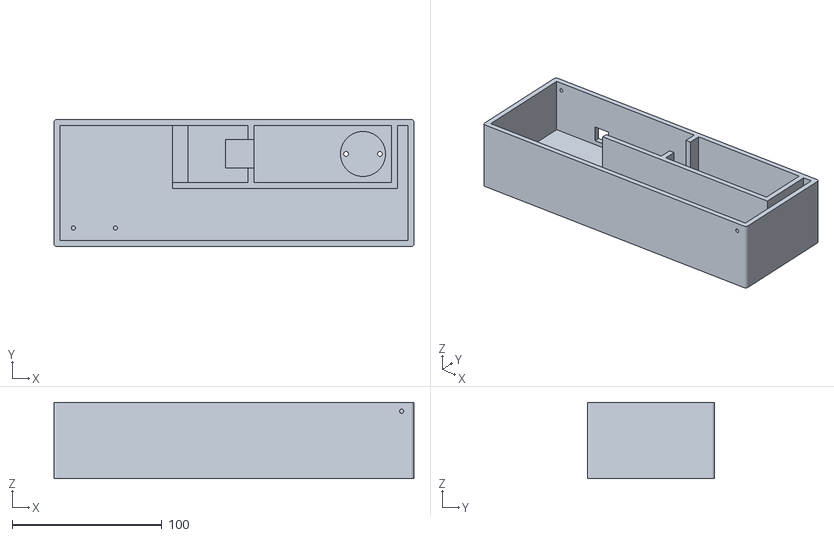
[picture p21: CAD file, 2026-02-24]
3DModels/STL/new_case-Lower_body.stl
240.0 x 85.0 x 51.0

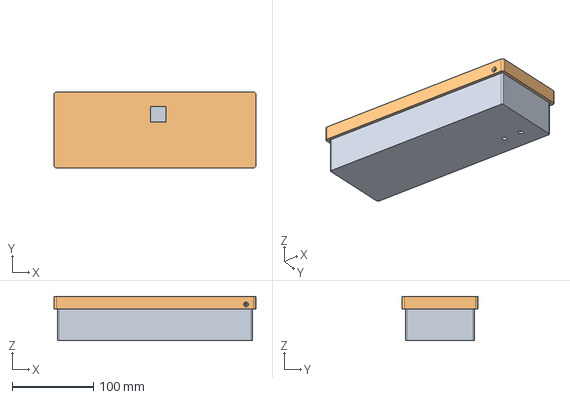
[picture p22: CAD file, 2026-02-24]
3DModels/FreeCAD/new_case.FCStd
248.0 x 93.0 x 54.5 mm
Lower_body
Upper_body

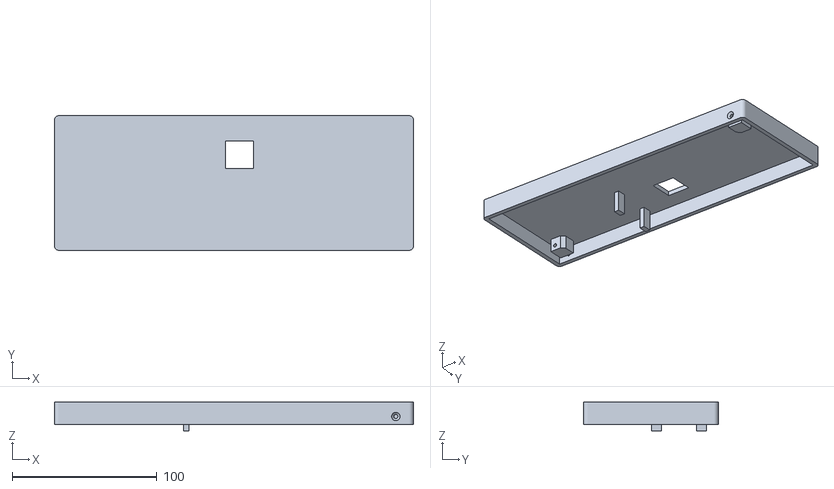
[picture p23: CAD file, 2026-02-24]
3DModels/STL/new_case-Upper_body.stl
248.0 x 93.0 x 20.0

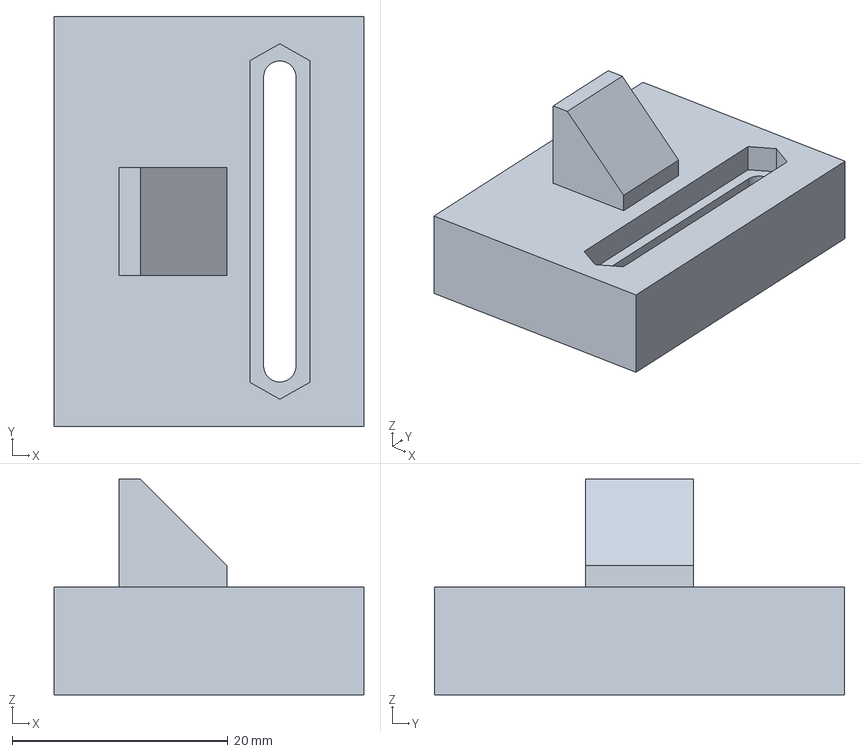
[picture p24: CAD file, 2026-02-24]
3DModels/FreeCAD/sensor_holder_2.FCStd
28.7 x 38.0 x 20.0 mm

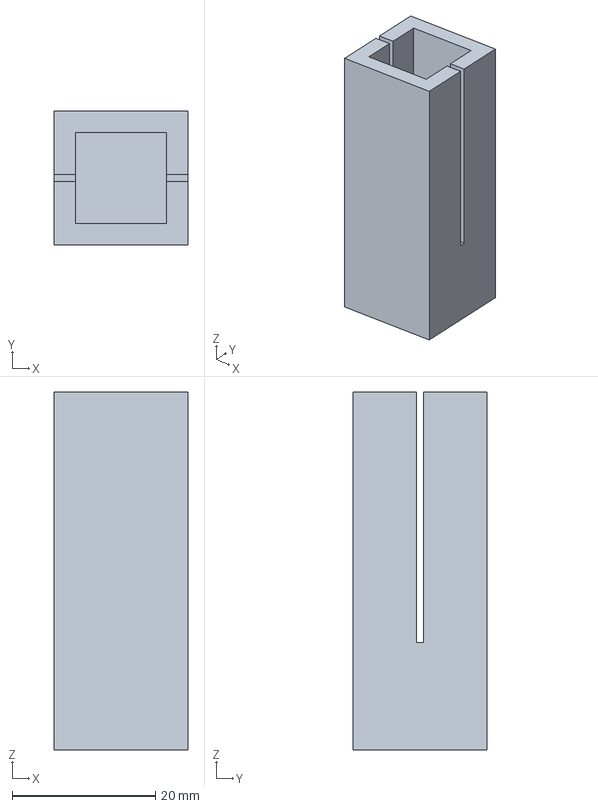
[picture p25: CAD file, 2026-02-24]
3DModels/FreeCAD/new_cuvette_holder.FCStd
18.7 x 18.7 x 50.0 mm

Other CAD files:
3DModels/STL/cap.stl
3DModels/STL/new_cuvette_holder.stl
3DModels/STL/sensor_holder_2.stl

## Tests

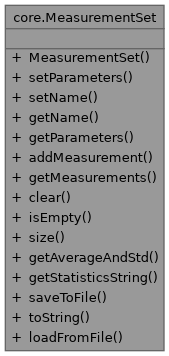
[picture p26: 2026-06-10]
Docs/html/classcore_1_1MeasurementSet__coll__graph.png

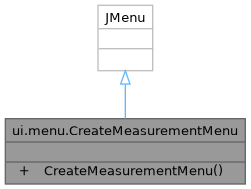
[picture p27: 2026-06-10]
Docs/html/classui_1_1menu_1_1CreateMeasurementMenu__coll__graph.png

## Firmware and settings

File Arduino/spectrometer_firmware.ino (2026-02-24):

#include <Wire.h>
#include "AS726X.h"

AS726X sensor;
String command = "";
const int BULB_PIN = 3;

// -------- DEFAULTS --------
int defaultIntegration = 50;   // ms
int defaultGain = 16;          // 1, 3, 16, 64
int defaultAvg = 1;            // number of measurements
bool defaultCalibrated = true;
int defaultLightInt = 50; // 0..100


void setup() {
  Serial.begin(115200);
  Wire.begin();

  if (!sensor.begin()) {
    while (1); // Sensor not found
  }

  pinMode(BULB_PIN, OUTPUT);
  int pwm = map(defaultLightInt, 0, 100, 0, 255);
  analogWrite(BULB_PIN, pwm);

  sensor.disableIndicator();
  sensor.disableBulb();

  Serial.println("READY");
}

void loop() {
  while (Serial.available()) {
    char c = Serial.read();
    if (c == '\n' || c == '\r') {
      handleCommand(command);
      command = "";
    } else {
      command += c;
    }
  }
}

// ---------------- COMMAND HANDLING ----------------

void handleCommand(String cmd) {
  cmd.trim();
  if (!cmd.startsWith("read")) return;

  // Start with defaults
  int integration = defaultIntegration;
  int gain = defaultGain;
  int avg = defaultAvg;
  bool calibrated = defaultCalibrated;
  int lightInt = defaultLightInt;

  // Remove "read"
  cmd = cmd.substring(4);
  cmd.trim();

  // Parse key=value pairs
  while (cmd.length() > 0) {
    int spaceIndex = cmd.indexOf(' ');
    String token;

    if (spaceIndex == -1) {
      token = cmd;
      cmd = "";
    } else {
      token = cmd.substring(0, spaceIndex);
      cmd = cmd.substring(spaceIndex + 1);
      cmd.trim();
    }

    int eqIndex = token.indexOf('=');
    if (eqIndex == -1) continue;

    String key = token.substring(0, eqIndex);
    String value = token.substring(eqIndex + 1);

    key.trim();
    value.trim();

    if (key == "int") {
      integration = value.toInt();
    } else if (key == "gain") {
      gain = value.toInt();
    } else if (key == "avg") {
      avg = value.toInt();
      if (avg < 1) avg = 1;
    } else if (key == "mode") {
      calibrated = (value == "cal");
    } else if (key == "light") {
      lightInt = value.toInt();
      if (lightInt < 0) lightInt = 0;
      if (lightInt > 100) lightInt = 100;
    }
  }

  // Apply settings
  sensor.setIntegrationTime(integration);
  uint8_t gainCode;
  if (gain <= 1) {
      gainCode = 0;            // 1x
  } else if (gain <= 4) {
      gainCode = 1;            // ~3.7x
  } else if (gain <= 16) {
      gainCode = 2;            // 16x
  } else {
      gainCode = 3;            // 64x
  }
  sensor.setGain(gainCode);

  int pwm = map(lightInt, 0, 100, 0, 255);
  analogWrite(BULB_PIN, pwm);

  // Take measurements
  takeAveragedMeasurement(avg, calibrated);
}

// ---------------- MEASUREMENT ----------------

void takeAveragedMeasurement(int avg, bool calibrated) {

  float sum[6] = {0, 0, 0, 0, 0, 0};

  for (int i = 0; i < avg; i++) {
    sensor.takeMeasurements();

    if (calibrated) {
      sum[0] += sensor.getCalibratedViolet();
      sum[1] += sensor.getCalibratedBlue();
      sum[2] += sensor.getCalibratedGreen();
      sum[3] += sensor.getCalibratedYellow();
      sum[4] += sensor.getCalibratedOrange();
      sum[5] += sensor.getCalibratedRed();
    } else {
      sum[0] += sensor.getViolet();
      sum[1] += sensor.getBlue();
      sum[2] += sensor.getGreen();
      sum[3] += sensor.getYellow();
      sum[4] += sensor.getOrange();
      sum[5] += sensor.getRed();
    }
  }

  // Output CSV
  for (int i = 0; i < 6; i++) {
    float value = sum[i] / avg;
    Serial.print(value, 3);
    if (i < 5) Serial.print(",");
  }
  Serial.println();
}

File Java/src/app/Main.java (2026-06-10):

package app;

import javax.swing.SwingUtilities;
import javax.swing.UIManager;
import ui.MainWindow;
import javax.swing.*;
import java.awt.*;

/**
 * Main application entry point.
 * Launches the spectrometer GUI.
 * 
 * @author Spectrometer Control Software
 * @version 1.0
 */
public class Main {

    /**
     * The main method that serves as the entry point for the application.
     * 
     * @param args command line arguments (not used)
     */
    public static void main(String[] args) {
        // Launch GUI on Event Dispatch Thread
        SwingUtilities.invokeLater(() -> {
            try {
                // Set system look and feel
                UIManager.setLookAndFeel(UIManager.getSystemLookAndFeelClassName());
            } catch (Exception e) {
                // Fall back to default look and feel
            }
            
            // Create and show main window
            MainWindow window = new MainWindow();
            window.setVisible(true);
        });
    }
}

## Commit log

2026-02-24 Initial commit: Arduino, Java, and 3D models
    [cap.FCStd, new_case.FCStd, new_cuvette_holder.FCStd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]
2026-02-24 Add README with project description + STL files
    [cap.stl, new_case-Lower_body.stl, new_case-Upper_body.stl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]
2026-02-24 wiring table added to readme
